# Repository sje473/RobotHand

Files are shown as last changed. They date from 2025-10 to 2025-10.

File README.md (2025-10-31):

# Robot Hand 🦾

This is my **Robot Hand project**, which I’ve been working on for a while.  
It’s been an awesome experience building and designing each part — from modeling the components to getting everything to move just right.

I had a ton of fun working on this project and learned a lot about mechanical design, electronics, and control systems along the way.  
I hope you enjoy checking it out as much as I enjoyed making it!

---

## 🎥 Demo Video

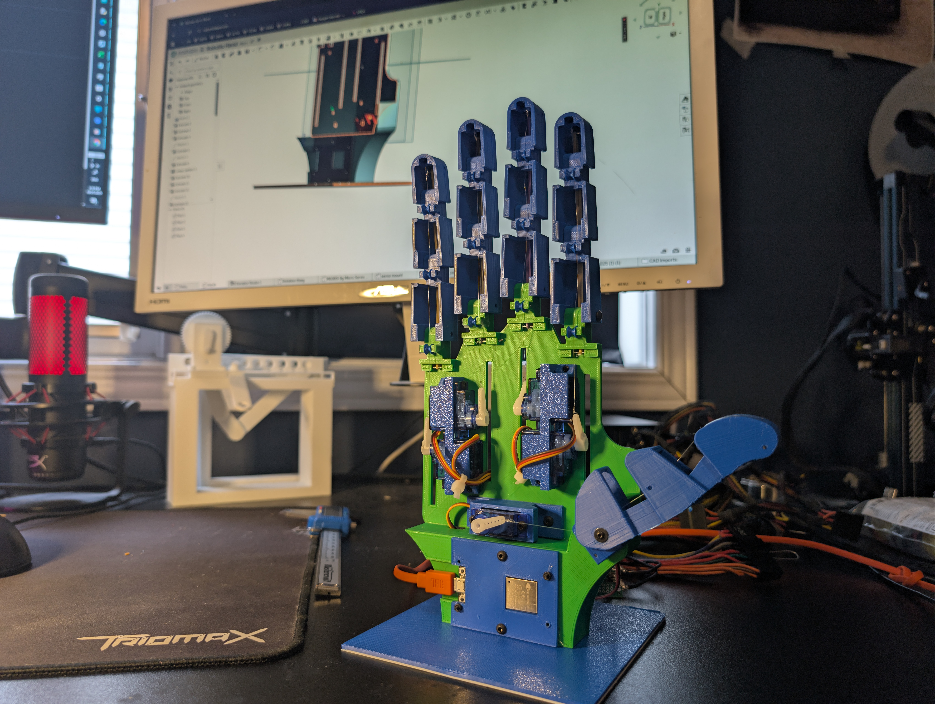
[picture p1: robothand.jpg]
Watch the demo video (https://www.youtube.com/watch?v=7yu-IW-gmXY)


---

## 🧩 Core Components

| Item | Part Name | Description | Unit Cost (CAD) | Qty | Cost (CAD) | Notes | Link |
|---|---|---|---:|----:|---:|---|---|
| 1 | Arduino Board | DOIT DEVIT V1 ESP32-WROOM-32 Development Board | $23.88 | 1 | $23.88 |  | [Amazon](https://www.amazon.ca/DIYmall-ESP-WROOM-32-Development-Bluetooth-Consumption/dp/B084KWNMM4/) |
| 2 | Servos | 5 PCS SG90 Servo Motors Kit Mini for Fixed Wing Helicopter Model QC | $3.40 | 5 | $16.99 |  | [Amazon](https://www.amazon.ca/dp/B0CXXPFNMF) |
| 3 | Rubber Bands | Officemate Assorted Size and Color Rubber Bands | $8.43 | 1 | $8.43 | Experiment with different bands to find adequate tension force | [Amazon](https://www.amazon.ca/Officemate-Assorted-Color-Rubber-82025/dp/B07QJH4NYQ/) |
| 4 | 3D Printer Filament | Bamboo PLA Basic Refill Filament 1.75mm | $35.99 | 1 | $35.99 | Entire design uses ~200 g (15 % infill) | [Amazon](https://www.amazon.ca/Bamboo-Refill-Filament-Printers-Printing/dp/B0FGQ2V2WH/) |
| 5 | String | Fishing Wire, Mckanti Fishing line Clear Nylon String 1640 FT | $9.99 | 1 | $9.99 |  | [Amazon](https://www.amazon.ca/Ranekie-Invisible-Resistant-monofilament-Decorations/dp/B098K3YH3M) |

**Total Cost:** ≈ $95.28 CAD

---

## ⚙️ Tools / Power

| Item | Part Name | Description | Unit Cost (CAD) | Qty | Cost (CAD) | Notes | Link |
|---|---|---|---:|----:|---:|---|---|
| 1 | 5 V > 5 A Power Source | YOOFONE 5 V 5 A 25 W AC/DC Adapter | $23.69 | 1 | $23.69 | Used 5 V rail from PSU; ensure enough current — each servo ≈ 1 A | [Amazon](https://www.amazon.ca/Adapter-100-240V-Converter-5-5x2-5mm-Security/dp/B0BZL1G6DS/) |
| 2 | 18 AWG Gauge Wire | Electrical Wire 18 AWG Silicone Wire 20 ft | $7.68 | 1 | $7.68 | For power line | [Amazon](https://www.amazon.ca/Electrical-Gauge-Silicone-Cable-Black/dp/B0746HMTPP) |
| 3 | Soldering Iron | TXINLEI Electronics Soldering Iron Kit 60 W 110 V | $13.99 | 1 | $13.99 |  | [Amazon](https://www.amazon.ca/TXINLEI-Electronics-Soldering-Adjustable-Temperature/dp/B08K8VFTF9) |
| 4 | Solder | TOWOT 63-37 High Purity Tin Lead Rosin Core | $12.99 | 1 | $12.99 |  | [Amazon](https://www.amazon.ca/TOWOT-Purity-Electrical-Soldering-Content/dp/B09KM2LW4G) |
| 5 | Assorted Kit of Nuts and Bolts | M2-M5 Cross Pan Head Screws Set | $13.99 | 1 | $13.99 |  | [Amazon](https://www.amazon.ca/Washers-Stainless-Machine-Commercial-Industrial/dp/B09X1G1ZV2) |

**Total Cost:** ≈ $72.34 CAD

---

📄 **[Download full BOM](BOM%20-%20Robot%20Hand.xlsx)**

---

*Thanks for checking out my project — I hope you like it!*

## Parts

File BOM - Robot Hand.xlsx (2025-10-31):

Core Components
 |  |  | CAD |  | CAD
Item Number | Part Name | Description | Unit Cost | Quantity | Cost | Notes | Link
1 | Arduino Board | DOIT DEVIT V1 ESP32-WROOM-32 Development Board | $23.88 | 1 | $23.88 |  | https://www.amazon.ca/DIYmall-ESP-WROOM-32-Development-Bluetooth-Consumption/dp/B084KWNMM4/
2 | Servos | 5 PCS SG90 Servo Motors Kit Mini for Fixed Wing Helicopter Model QC | $3.40 | 5 | $16.99 |  | https://www.amazon.ca/dp/B0CXXPFNMF
3 | Rubber Bands | Officemate Assorted Size and Color Rubber Bands | $8.43 | 1 | $8.43 | (Experiment with different bands to find adequate tension force) | https://www.amazon.ca/Officemate-Assorted-Color-Rubber-82025/dp/B07QJH4NYQ/
4 | 3D Printer Filament | Bamboo PLA Basic Refill Filament 1.75mm 1 | $35.99 | 1 | $35.99 | Wont use the entire roll, entire design uses roughly 200g (15% infill) | https://www.amazon.ca/Bamboo-Refill-Filament-Printers-Printing/dp/B0FGQ2V2WH/
5 | String | Fishing Wire, Mckanti Fishing line Clear Nylon String 1640 FT | $9.99 | 1 | $9.99 |  | https://www.amazon.ca/Ranekie-Invisible-Resistant-monofilament-Decorations/dp/B098K3YH3M
 |  | Total Cost |  |  | $95.28
Tools / Power
Item Number | Part Name | Description | Unit Cost | Quantity | Cost | Notes | Link
1 | 5V >5A Power Source | YOOFONE 5V Power Supply 5A 25W AC/DC Adapter | $23.69 | 1 | $23.69 | I used the 5V rail on a spare PSU I had laying around, what matters is that you have enough current, each servo requires at least 1A of current dedicated for safety | https://www.amazon.ca/Adapter-100-240V-Converter-5-5x2-5mm-Security/dp/B0BZL1G6DS/
3 | 18AWG Gauge Wire | Electrical Wire 18 AWG 18 Gauge Silicone Wire Hook Up wire Cable 20 Feet | $7.68 | 1 | $7.68 | (for power line) | https://www.amazon.ca/Electrical-Gauge-Silicone-Cable-Black/dp/B0746HMTPP
3 | Soldering Iron | TXINLEI Electronics Soldering Iron Kit，60W 110V Adjustable Temperature | $13.99 | 1 | $13.99 |  | https://www.amazon.ca/TXINLEI-Electronics-Soldering-Adjustable-Temperature/dp/B08K8VFTF9
3 | Solder | TOWOT 63-37 High Purity Tin Lead Rosin Core Solder Wire for Electrical Soldering | $12.99 | 1 | $12.99 |  | https://www.amazon.ca/TOWOT-Purity-Electrical-Soldering-Content/dp/B09KM2LW4G
3 | Assorted Kit of Nuts and Bolts | Bolts and Nuts Set,M2 M2.5 M3 M4 M5 Cross Pan Head Screws | $13.99 | 1 | $13.99 |  | https://www.amazon.ca/Washers-Stainless-Machine-Commercial-Industrial/dp/B09X1G1ZV2
 |  | Total Cost |  |  | $72.34

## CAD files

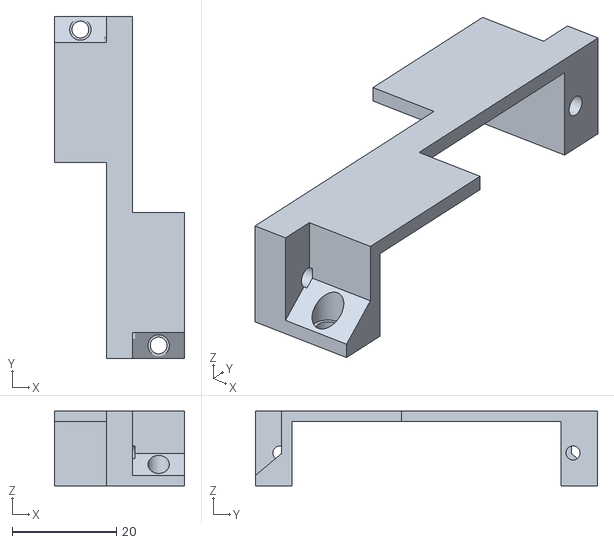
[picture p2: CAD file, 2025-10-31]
Parts/Mount 1.stl
25.0 x 65.6 x 14.3

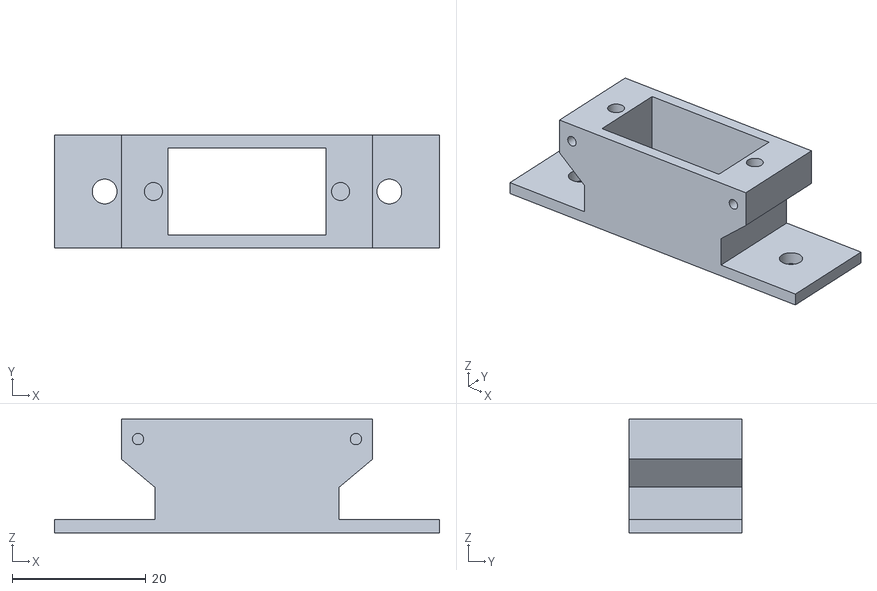
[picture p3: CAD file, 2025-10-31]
Parts/Mount 3.stl
57.6 x 17.0 x 17.0

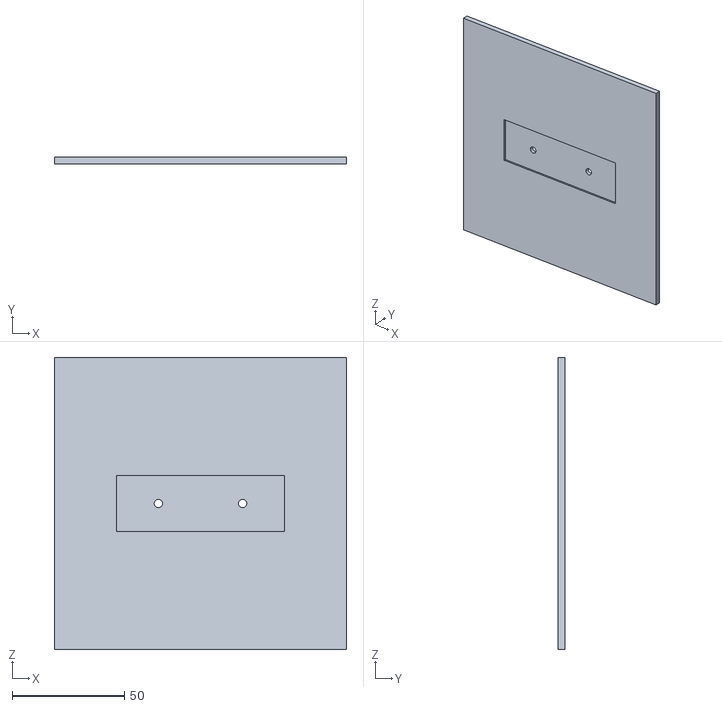
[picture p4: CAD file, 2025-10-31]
Parts/Floor.stl
130.0 x 3.00 x 130.0

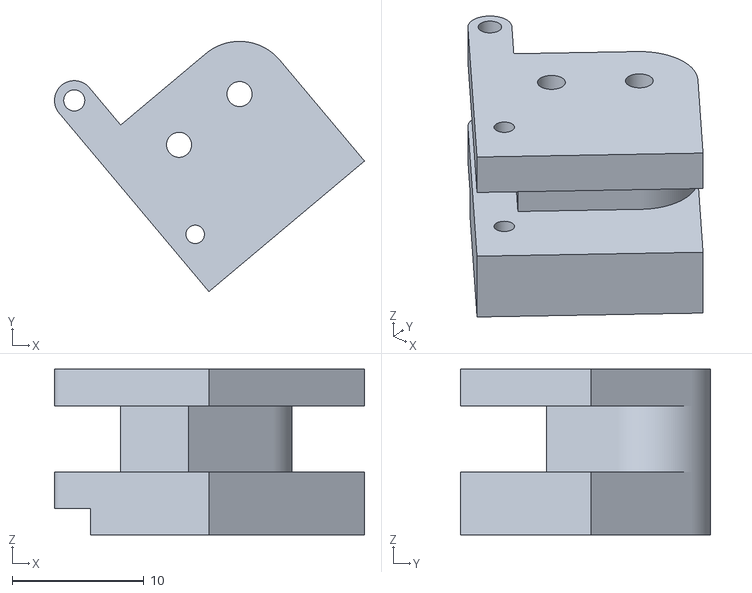
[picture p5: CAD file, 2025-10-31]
Parts/Thumb Piece.stl
23.5 x 19.0 x 12.6

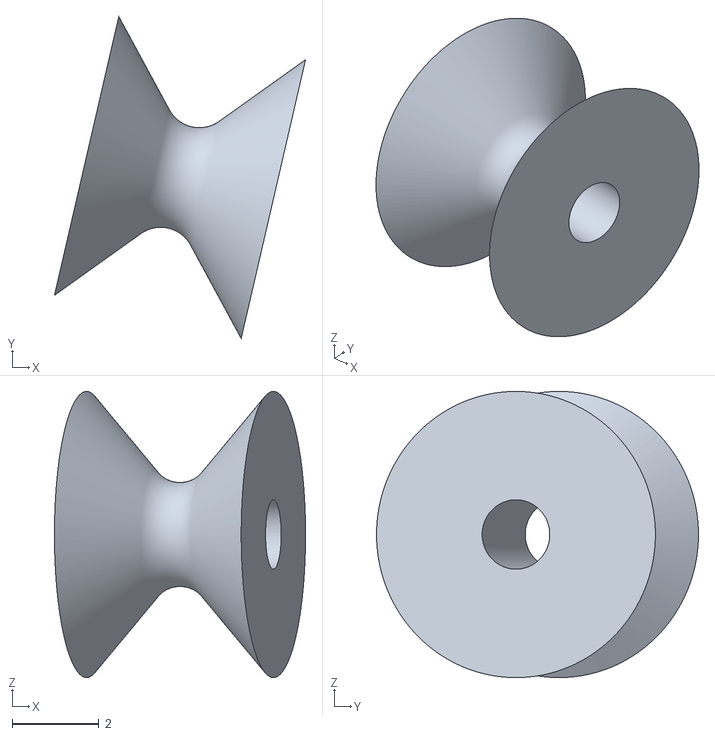
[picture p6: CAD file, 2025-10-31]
Parts/Pully.stl
5.79 x 7.43 x 6.60

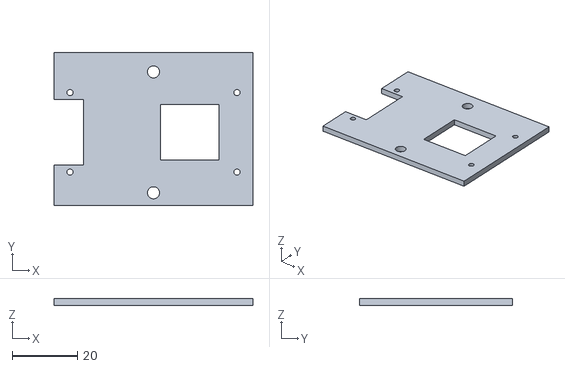
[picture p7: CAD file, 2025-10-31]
Parts/Arduino Cover.stl
61.0 x 47.0 x 2.00

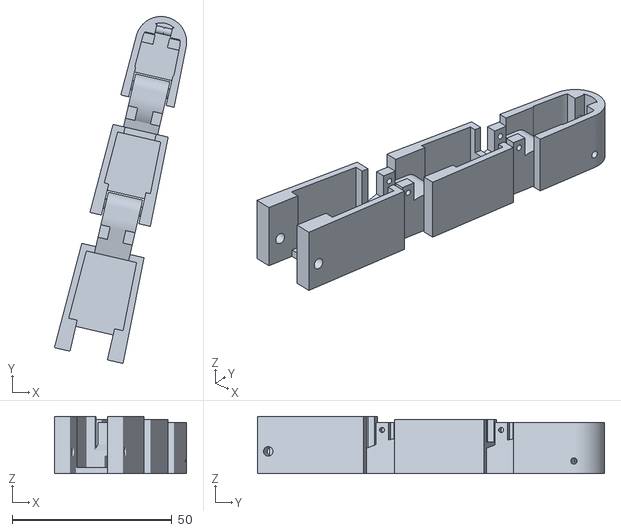
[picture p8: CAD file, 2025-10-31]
Parts/Finger.stl
41.4 x 108.6 x 18.0

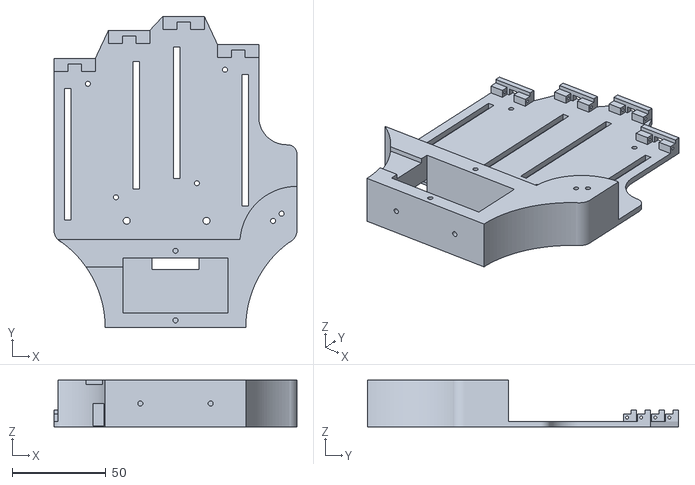
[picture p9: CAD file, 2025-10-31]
Parts/Palm.stl
129.6 x 166.1 x 25.0

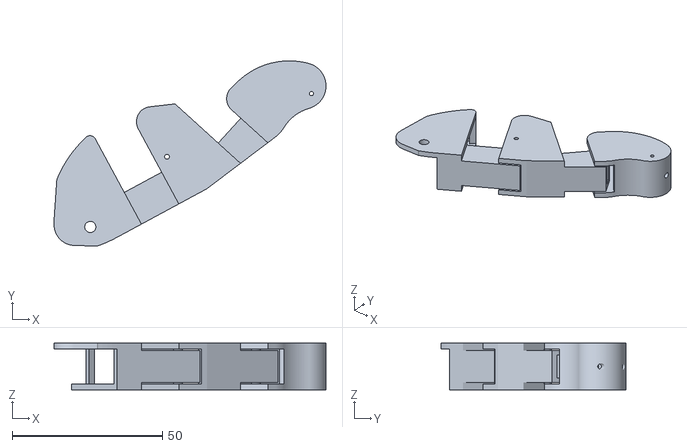
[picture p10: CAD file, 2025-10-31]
Parts/Thumb.stl
90.6 x 61.7 x 15.6

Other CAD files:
Parts/Mount 2.stl

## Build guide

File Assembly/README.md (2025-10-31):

# 🧠 Assembly Overview

Welcome to the **Assembly Section** of the Robot Hand project!

Before diving into any specific component assembly, make sure to follow each section **in the correct order** — each step builds on the last.  
This will ensure proper alignment, tension, and motion throughout the final assembly.

---

## 🔧 Recommended Assembly Order

1. **[Finger Assembly](./fingerAssembly.md)**  
   Begin by assembling all four fingers, installing the pulleys, tensioning the elastic bands, and threading the base holes to the palm.

2. **[Thumb Assembly](./thumbAssembly.md)**  
   Assemble the thumb and its anchor piece. Similar to the fingers but with minor differences in pulley locations and tensioning setup.

3. **[Servo Mounting & Actuation String](./servoMounting.md)**  
   Mount all servos to the palm, route the wires, and connect nylon strings to each finger and thumb.  
   This connects the mechanical assembly to the actuation system.

4. **[Power Setup](./powerSetup.md)**  
   Wire your power source, ensuring safe 5V power distribution for all servos and the control board.

5. **[Arduino Cover + Floor Assembly](./coverAndFloor.md)**  
   Final structural step — install the cover plates, secure the Arduino, and tidy up your wiring to complete the build.

---

## ⚠️ Important Notes
- Follow the order **exactly** — skipping steps can make tensioning or alignment difficult later.  
- Each guide includes part-specific notes, hardware requirements, and tips for smoother motion.  
- Ensure all pulleys rotate freely before connecting strings or applying power.

---

Once complete, your hand will be fully assembled and ready for calibration and testing.

Happy building! 🦾

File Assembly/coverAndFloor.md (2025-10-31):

# 🧱 Arduino Cover & Floor Assembly

### Overview
This is the final stage of the Robot Hand assembly.  
You’ll secure the Arduino to its cover, mount it into the wrist, attach the cover to the palm, and finally install the floor plate.  
Once complete, your hand will be fully enclosed, powered, and ready for programming.

---

### Materials Needed
- 1 × Arduino/ESP32 board  
- 1 × Arduino cover  
- 1 × Floor plate  
- 4 × M2 × 8 mm bolts + nuts (for mounting the Arduino)  
- 2 × M3 × 8 mm bolts (for attaching the Arduino cover to the palm)  
- 2 × M3 × 8 mm bolts (for attaching the floor plate)  
- Screwdriver and small wrench  

---

### 1. Mount the Arduino to the Cover
1. Position the Arduino board on the **Arduino cover**.  
2. Secure it using **4 × M2 × 8 mm bolts**, with the **bolt heads facing inward** (inside the wrist cavity).  
   - The **nuts should be on the outside** of the hand — this ensures the cover sits flush inside the wrist later.  
3. Verify that the USB port on the Arduino lines up with the access hole on the cover.

---

### 2. Install the Arduino Assembly Into the Wrist
1. Carefully place the Arduino and cover assembly into the **wrist cavity** of the palm.  
2. Align the mounting holes on the cover with the **threaded holes in the palm**.  
3. Secure the cover to the palm using **2 × M3 × 8 mm bolts** screwed **directly into the plastic**.  
4. Confirm that the fit is snug and that the USB port remains accessible from the wrist opening.

---

### 3. Attach the Floor Plate
1. Position the **floor plate** under the palm.  
2. Make sure the side with the **recessed rectangular section** is **facing downward** (toward the bottom of the hand).  
3. Fasten it using **2 × M3 × 8 mm bolts**.  
4. Verify that all edges are flush and the assembly feels solid.

---

### 4. Power and Final Setup
1. Connect your **micro-USB cable** to the Arduino/ESP32.  
2. Turn on your **5 V power source**.  
3. The hand should now power up — it’s **plug-and-play** from here.  
4. Upload your control code, calibrate your servos, and enjoy your working robotic hand!

---

**Tip:** Before powering on, double-check that no wires are pinched between the cover and palm, and that the USB cable fits comfortably without bending.

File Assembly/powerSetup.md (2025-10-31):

# ⚡ Power Setup

### Overview
This section covers how to properly wire and power the servos and control system for the Robot Hand.  
You’ll be connecting your 5 V power supply, distributing current through 18 AWG wiring, and soldering the servo power, ground, and signal leads to their respective connections on the ESP32 board.

---

### Materials Needed
- 18 AWG silicone wire (red for power, black for ground)
- 5 V ≥ 5 A power source  
- 5 × SG90 servo motors  
- Soldering iron and solder  
- Wire cutters and strippers  
- Heat-shrink tubing or electrical tape  

---

### 1. Prepare the Power Leads
1. Cut two lengths of **18 AWG wire** — one for **power (red)** and one for **ground (black)**.  
2. **Solder these wires directly to your power source**, connecting:  
   - Red → **5 V output**  
   - Black → **Ground (GND)**  
3. Ensure your joints are solid and insulated properly.

---

### 2. Prepare the Servo Wires
1. Cut off the **female connectors** from each servo cable.  
2. Separate the three wires in each servo cable:
   - **Red** → Power  
   - **Brown or Black** → Ground  
   - **Yellow or Orange** → Signal  
3. Strip a small section of insulation off each end for soldering.

---

### 3. Power Distribution
1. Solder all **servo red wires** to the **18 AWG power line**.  
2. Solder all **servo brown/black wires** to the **18 AWG ground line**.  
3. **Add one extra wire from the 18 AWG ground line** and solder its other end to a **GND pin on the Arduino/ESP32**.  
   - This connects the Arduino ground to the servo ground, ensuring all components share a **common electrical reference**.  
4. Double-check polarity before applying power — reversing power and ground will damage servos.  
5. Optionally, apply heat-shrink tubing over each joint for safety and durability.

---

### 4. Signal Wiring and Routing
1. Route all **servo signal wires (yellow)** through the **hole on the back of the wrist**, leading into the **large wrist cavity** where the Arduino/ESP32 is mounted.  
2. Once the wires reach the control board area, solder each **signal wire** to the corresponding **GPIO pin**:

| Servo | GPIO Pin |
|---|---|
| Pinky | GPIO 27 |
| Ring | GPIO 26 |
| Middle | GPIO 25 |
| Index | GPIO 33 |
| Thumb | GPIO 32 |

3. Keep wires tidy and ensure no bare connections are exposed.

---

### 5. Verification
- Before powering on, confirm:
  - 5 V and GND are consistent across all servos.  
  - The **Arduino ground** is properly connected to the shared ground line.  
  - Signal wires are connected to the correct pins.  
  - No short circuits between power and ground.  
- Power up the system and gently test each servo to ensure movement.

---

**Tip:** If the servos jitter or reset, your power source may be under-rated. Each servo can draw up to **1 A under load**, so aim for **at least 5 A continuous current** capability.

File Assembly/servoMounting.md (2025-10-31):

## ⚙️ Servo Mounting & Actuation String Setup

### Overview
This stage covers **mounting all five servos** and setting up the **actuation strings** for each finger and thumb.  
There are **three different servo mounts**:  
- Two long mounts (for the four fingers)  
- One dedicated mount for the thumb servo.  

Each servo will later pull on the nylon strings that run under the pulleys to bend the fingers and thumb.

---

### Materials Needed
- 5 × SG90 micro servos  
- 2 × long servo mounts (for fingers)  
- 1 × thumb servo mount  
- 4 × M2 × 8 mm bolts + nuts (for each finger servo mount)  
- 4 × M3 × 8 mm bolts (for thumb mount)  
- Nylon string (fishing line)  
- Zip ties  
- Screwdriver and cutters/pliers  

---

### 1. Mount the Finger Servos

1. Use the **two long servo mounts** (Mount 1 and Mount 2) — each holds **two servos**.  
2. Mount orientation:  
   - The **pinky** and **index** servos should be **furthest from the top** of the palm.  
   - The **middle** and **ring** finger servos should be **closest to the top** of the palm.  
3. Position each servo so that its **arm (horn)** is **closest to the middle** of the mount.  
4. Secure each servo mount to the **palm** using **4 × M2 × 8 mm bolts and nuts**.  
5. Check that the servos sit flush and their arms have clear rotation paths.

---

### 2. Mount the Thumb Servo

1. Use the **dedicated thumb servo mount**.  
2. Mount it to the palm using **4 × M3 × 8 mm bolts**, which screw directly into the mount and palm.  
3. Make sure the **hole on the side** of the mount faces the **hole on the wrist** — this is important for wire routing later.  
4. The thumb servo should rotate freely without interference.

---

### 3. Wire Routing

1. **Cut off the female connectors** from each servo wire (to make routing easier).  
2. For the **finger servos**, route the wires **through the hole nearest the center** of the palm.  
   - Use **zip ties** to group each pair of finger servos neatly.  
3. For the **thumb servo**, route its wire through the **hole in the wrist** of the hand.  
4. Once all wires are routed, tidy them with additional zip ties if needed.

---

### 4. Connect the Servo Arms

1. Attach the **servo arms (horns)** that came with the servo pack onto each servo.  
2. Using your **nylon string**, tie a small **knot around the last hole** on each servo arm.  
3. Feed the nylon string through the hand, ensuring it passes **under every pulley** on its corresponding finger or thumb.  
   - The pulleys are there to **reduce friction** and guide the string along the correct path.  

---

### 5. Threading and Tensioning the Strings

#### For the Fingers
1. Feed the nylon string through all pulleys until you reach the **tip of the finger**.  
2. At the fingertip, locate the **small rod** — wrap the string around it and tie a secure knot.  
3. Adjust the knot so that when the servo arm is **parallel to the finger**, the string is already slightly **under tension**.  
   - This ensures the finger responds immediately when the servo moves.  
4. Repeat for all **four fingers**.

#### For the Thumb
1. Feed the string starting at the **tip of the thumb** — this makes it easier to thread through the hole.  
2. There’s a **small hole at the thumb tip** instead of a rod — tie the string through this hole securely.  
3. Feed the string back through the pulleys on the thumb and toward the servo arm.  
4. Attach the end of the string to the **last hole on the servo arm**, ensuring that when the arm is **horizontal**, the string has **slight tension**.  
5. Verify that the thumb bends smoothly and returns upright when released.

---

### 6. Final Check

- Confirm that:
  - Each string runs **under all pulleys**.  
  - Strings have **even, light tension** when servos are in their neutral positions.  

---

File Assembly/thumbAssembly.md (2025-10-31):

## 👍 Thumb Assembly Instructions

### Overview
Like the fingers, the thumb is printed as a **print-in-place mechanism**, using built-in pin joints for its motion.  
The **pulleys** are added to reduce friction for the actuation string that will later drive the thumb movement.

---

### Materials Needed
- Thumb  
- Thumb piece (anchor joint that attaches to the palm)  
- 3 pulleys (one located on the thumb piece)  
- Elastic band  
- Metal paper clips (>1 mm diameter)  
- Two M2 × 16 mm screws  
- One M2 × 10 mm screw  
- Nylon string (fishing line)  
- Screwdriver and cutters/pliers  

---

### 1. Install the Pulleys
1. Cut **three (3)** paper clip pins — two **8 mm** and one **12 mm** in length.  
   - The **first pulley** will be installed on the **thumb piece**, and the other **two** on the **thumb**.  
2. Feed each pin through its pulley once to remove any 3D printing roughness.  
3. At each joint, position the pulley between the pin slots, then insert the pin so it can spin freely but stay in place.  
4. Verify that all pulleys rotate smoothly — they’ll later guide the actuation string to minimize friction during motion.

---

### 2. Attach the Thumb to the Thumb Piece
1. Once pulleys are installed, align the thumb and thumb piece so the pin holes line up.  
2. Insert an **M2 × 10 mm screw** through the holes — this acts as a **pin joint**.  
3. Do **not fully tighten**; leave a slight gap for free rotation.

---

### 3. Mount the Thumb Piece to the Palm
1. Before threading the elastic band, attach the thumb piece to the **palm** using **two (2) M2 × 16 mm screws** from underneath the palm.  
2. Ensure the **pin slot on the thumb piece** faces toward the **center of the palm** for proper range of motion and band routing.

---

### 4. Install the Elastic Band
1. Position the elastic band inside the thumb so it follows the pulley path.  
2. At the **tip**, locate the small side hole.  
   - Insert an **8 mm pin** through that hole and through the elastic band to anchor it under tension.  
3. Tie the **nylon string** securely to the elastic band.  
4. Feed the string down through the thumb’s internal holes toward the palm.  
5. At the palm, insert the **12 mm pin** through the band’s end hole on the thumb piece.  
   - This creates pre-tension, allowing the thumb to spring back to its neutral position when released.

---

### 5. Verify Motion
- Manually bend and release the thumb to ensure:
  - The pulleys rotate freely.  
  - The band stretches evenly.  
  - The thumb returns upright without sticking.

---

**Tip:** Apply a small amount of lubricant to the pulley axles if movement feels rough — this keeps future string motion smooth and low-friction.

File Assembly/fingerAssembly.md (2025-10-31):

## 🖐️ Finger Assembly Instructions

### Overview
The finger is designed as a **print-in-place mechanism**, meaning the joints are already functional when printed.  
Its motion relies on **built-in pin joints** for rotation, while the **pulleys** are installed afterward to reduce friction once the actuation string is added later.

---

### Materials Needed
- Metal paper clips (>1 mm diameter)  
- Rubber bands (elastic)  
- Nylon string (fishing line)  
- Wire cutters or pliers  

---

### Steps

1. **Prepare the Pins**  
   - Cut **four (4)** paper clip sections to **8 mm** length.  
   - Cut **one (1)** section to **12 mm** length.  

2. **Deburr the Pulley Holes**  
   - Feed each 8 mm pin through the pulleys to clean up any 3D printing residue or tight tolerances.  
   - Remove the pins once the pulleys rotate freely.

3. **Install the Pulley Joints**  
   - Each joint of the finger has **pin slots**.  
   - Position a pulley between the pin slots, then insert one 8 mm pin through.  
   - The fit should be tight enough that:
     - The pulley spins freely, **and**
     - The pin doesn’t fall out when the finger is tilted.  
   - Repeat for all **three joints** along the finger.  
   - These pulleys will later guide the actuation string to minimize friction during movement.

4. **Attach the Elastic Band**  
   - You should have one 8 mm pin and one 12 mm pin remaining.  
   - At the **tip of the finger**, locate the small hole on the side.  
   - Insert the **8 mm pin** through that hole and through a loop of the elastic band — this will create tension when pulled.

5. **Feed and Anchor the Nylon String**  
   - Tie the **nylon string** securely around the elastic band.  
   - Feed the string through the **holes at the base of each finger**, which connect the finger to the palm.  
   - Pull gently to check that the band tensions smoothly.

6. **Tension the Band at the Palm**  
   - Locate the **final pin slot** on the palm.  
   - Insert the **12 mm pin** through the elastic band loop here.  
   - This creates the restoring force that makes the finger return upright after being bent.

7. **Repeat for All Fingers**  
   - Repeat this entire process for all four fingers.  
   - Ensure pulleys rotate freely and that each band provides smooth, even tension.

---

**Tip:** A drop of light oil or graphite powder can help pulleys spin more smoothly and reduce long-term string wear.

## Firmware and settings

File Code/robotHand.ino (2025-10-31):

#include <ESP32Servo.h>

// ======= QUICK SERVO ENABLES =======
#define USE_THUMB   true
#define USE_INDEX   true
#define USE_MIDDLE  true
#define USE_RING    true
#define USE_PINKY   true
// ===================================


const int abortPin = 0;     // BOOT button on ESP32 DevKit V1
const int step = 10;

// Create servo objects
Servo thumbServo;
Servo indexServo;
Servo middleServo;
Servo ringServo;
Servo pinkyServo;

// Pin assignments
const int THUMB_PIN = 32;
const int INDEX_PIN = 33;
const int MIDDLE_PIN = 25;
const int RING_PIN = 26;
const int PINKY_PIN = 27;

// Status strings
String thumbStatus = "";
String indexStatus = "";
String middleStatus = "";
String ringStatus = "";
String pinkyStatus = "";

void setup() {
  Serial.begin(9600);
  
  // Attach only the enabled servos
  if (USE_THUMB)  thumbServo.attach(THUMB_PIN);
  if (USE_INDEX)  indexServo.attach(INDEX_PIN);
  if (USE_MIDDLE) middleServo.attach(MIDDLE_PIN);
  if (USE_RING)   ringServo.attach(RING_PIN);
  if (USE_PINKY)  pinkyServo.attach(PINKY_PIN);

  // Initialize to open
  if (USE_THUMB)  thumbServo.write(0);
  if (USE_INDEX)  indexServo.write(0);
  if (USE_MIDDLE) middleServo.write(0);
  if (USE_RING)   ringServo.write(0);
  if (USE_PINKY)  pinkyServo.write(0);
}

void loop() {
  if (digitalRead(abortPin) == LOW) abortNow();
  if (Serial.available() > 0) {
    String data = Serial.readStringUntil('\n');
    
    // Parse format: T:status,I:status,M:status,R:status,P:status
    parseStatuses(data);
    
    // Convert to servo angles
    if (USE_THUMB)  thumbServo.write(getAngle(thumbStatus));
    if (USE_INDEX)  indexServo.write(getAngle(indexStatus));
    if (USE_MIDDLE) middleServo.write(getAngle(middleStatus));
    if (USE_RING)   ringServo.write(getAngle(ringStatus));
    if (USE_PINKY)  pinkyServo.write(getAngle(pinkyStatus));
  }
}

void abortNow() {
  Serial.println("ABORT PRESSED — stopping servos.");
  if (USE_THUMB)  thumbServo.detach();
  if (USE_INDEX)  indexServo.detach();
  if (USE_MIDDLE) middleServo.detach();
  if (USE_RING)   ringServo.detach();
  if (USE_PINKY)  pinkyServo.detach();
  while (true) delay(100);
}

void parseStatuses(String data) {
  int startIdx = 0;
  int commaIdx = 0;
  
  while (commaIdx != -1) {
    commaIdx = data.indexOf(',', startIdx);
    String segment = (commaIdx == -1) ? data.substring(startIdx) : data.substring(startIdx, commaIdx);
    
    int colonIdx = segment.indexOf(':');
    if (colonIdx != -1) {
      String finger = segment.substring(0, colonIdx);
      String status = segment.substring(colonIdx + 1);
      
      if (finger == "T") thumbStatus = status;
      else if (finger == "I") indexStatus = status;
      else if (finger == "M") middleStatus = status;
      else if (finger == "R") ringStatus = status;
      else if (finger == "P") pinkyStatus = status;
    }
    
    startIdx = commaIdx + 1;
  }
}

int getAngle(String status) {
  if (status == "Straight" || status == "Not Swept") {
    return 0;
  } 
  else if (status == "Half Bent" || status == "Half Swept") {
    return 90;
  } 
  else {
    return 170;
  }
}

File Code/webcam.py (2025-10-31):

import cv2
import mediapipe as mp
from collections import deque
import serial
import time

# Initialize serial connection to Arduino
try:
    arduino = serial.Serial('COM10', 9600, timeout=1)
    time.sleep(2)
    print("Connected to Arduino!")
except:
    print("Could not connect to Arduino. Running without serial.")
    arduino = None

# Status history buffers for smoothing
BUFFER_SIZE = 10
THUMB_BUFFER_SIZE = 3  # shorter buffer for more responsive thumb
thumb_history = deque(maxlen=THUMB_BUFFER_SIZE)
index_history = deque(maxlen=BUFFER_SIZE)
middle_history = deque(maxlen=BUFFER_SIZE)
ring_history = deque(maxlen=BUFFER_SIZE)
pinky_history = deque(maxlen=BUFFER_SIZE)

def get_smoothed_status(history_buffer):
    if len(history_buffer) == 0:
        return "Unknown"
    status_counts = {}
    for status in history_buffer:
        status_counts[status] = status_counts.get(status, 0) + 1
    return max(status_counts, key=status_counts.get)

# Initialize MediaPipe
mp_hands = mp.solutions.hands
mp_drawing = mp.solutions.drawing_utils
mp_drawing_styles = mp.solutions.drawing_styles

hands = mp_hands.Hands(
    static_image_mode=False,
    max_num_hands=1,
    min_detection_confidence=0.5,
    min_tracking_confidence=0.5
)

# ---- Camera open (robust) ----
def open_camera():
    # Try common backends on Windows and a few indices
    backends = [cv2.CAP_DSHOW, cv2.CAP_MSMF, cv2.CAP_ANY]
    indices = [0, 1, 2, 3]
    for be in backends:
        for idx in indices:
            cap = cv2.VideoCapture(idx, be)
            if cap.isOpened():
                ok, _ = cap.read()
                if ok:
                    print(f"Camera opened on index {idx} (backend {be}).")
                    # Optional: request MJPG for smoother capture if supported
                    cap.set(cv2.CAP_PROP_FOURCC, cv2.VideoWriter_fourcc(*'MJPG'))
                    return cap
                cap.release()
    return None

webcam = open_camera()
if webcam is None:
    print("ERROR: Could not open any camera. "
          "Close apps using the camera (Zoom/Teams/OBS/Browser), "
          "then check Windows Settings > Privacy & security > Camera "
          "and allow desktop apps. Try replugging the webcam.")
    hands.close()
    raise SystemExit

def get_finger_bend_status(hand_landmarks, finger_name):
    wrist = hand_landmarks.landmark[mp_hands.HandLandmark.WRIST]
    if finger_name == "INDEX":
        tip = hand_landmarks.landmark[mp_hands.HandLandmark.INDEX_FINGER_TIP]
        pip = hand_landmarks.landmark[mp_hands.HandLandmark.INDEX_FINGER_PIP]
        mcp = hand_landmarks.landmark[mp_hands.HandLandmark.INDEX_FINGER_MCP]
    elif finger_name == "MIDDLE":
        tip = hand_landmarks.landmark[mp_hands.HandLandmark.MIDDLE_FINGER_TIP]
        pip = hand_landmarks.landmark[mp_hands.HandLandmark.MIDDLE_FINGER_PIP]
        mcp = hand_landmarks.landmark[mp_hands.HandLandmark.MIDDLE_FINGER_MCP]
    elif finger_name == "RING":
        tip = hand_landmarks.landmark[mp_hands.HandLandmark.RING_FINGER_TIP]
        pip = hand_landmarks.landmark[mp_hands.HandLandmark.RING_FINGER_PIP]
        mcp = hand_landmarks.landmark[mp_hands.HandLandmark.RING_FINGER_MCP]
    elif finger_name == "PINKY":
        tip = hand_landmarks.landmark[mp_hands.HandLandmark.PINKY_TIP]
        pip = hand_landmarks.landmark[mp_hands.HandLandmark.PINKY_PIP]
        mcp = hand_landmarks.landmark[mp_hands.HandLandmark.PINKY_MCP]
    else:
        return "Unknown"
    tip_dist = ((tip.x - wrist.x)**2 + (tip.y - wrist.y)**2 + (tip.z - wrist.z)**2)**0.5
    pip_dist = ((pip.x - wrist.x)**2 + (pip.y - wrist.y)**2 + (pip.z - wrist.z)**2)**0.5
    if tip_dist > pip_dist * 1.15:
        return "Straight"
    elif tip_dist > pip_dist * 1.05:
        return "Half Bent"
    else:
        return "Bent"

def get_thumb_sweep_status(hand_landmarks):
    """Determines if thumb is swept across palm or not (sensitive but not stuck)"""
    thumb_tip = hand_landmarks.landmark[mp_hands.HandLandmark.THUMB_TIP]
    thumb_cmc = hand_landmarks.landmark[mp_hands.HandLandmark.THUMB_CMC]
    wrist = hand_landmarks.landmark[mp_hands.HandLandmark.WRIST]
    middle_mcp = hand_landmarks.landmark[mp_hands.HandLandmark.MIDDLE_FINGER_MCP]

    thumb_extension = abs(thumb_tip.x - wrist.x)
    base_extension  = abs(thumb_cmc.x - wrist.x)
    extension_ratio = thumb_extension / base_extension if base_extension > 1e-6 else 1.0

    palm_size = ((middle_mcp.x - wrist.x)**2 + (middle_mcp.y - wrist.y)**2 + (middle_mcp.z - wrist.z)**2)**0.5 + 1e-6
    y_gap_norm = abs(thumb_tip.y - middle_mcp.y) / palm_size

    if (extension_ratio < 1.05) and (y_gap_norm < 0.50):
        return "Fully Swept"
    elif (extension_ratio < 1.70) and (y_gap_norm < 0.50):
        return "Half Swept"
    else:
        return "Not Swept"

# ---- Fullscreen window (added) ----
WINDOW_NAME = "Hand Tracking - Press 'q' to quit"
cv2.namedWindow(WINDOW_NAME, cv2.WINDOW_NORMAL)
cv2.setWindowProperty(WINDOW_NAME, cv2.WND_PROP_FULLSCREEN, cv2.WINDOW_FULLSCREEN)
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

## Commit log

2025-10-31 Add files via upload
    arduino code
2025-10-31 Create servoMounting
